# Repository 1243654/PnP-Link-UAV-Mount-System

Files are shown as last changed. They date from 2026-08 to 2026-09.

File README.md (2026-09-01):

# PnP-Link-UAV-Mount-System
无人机多兼容智能挂载系统，包含机械脱钩结构设计、控制固件与通信协议。本项目为 2026 中美创客大赛参赛作品，按赛事开源评分要求完整公开全部技术方案。

## 项目概述
本项目完整名称为**多兼容型智能无人机挂载系统**完整英文名为“Multi-Compatible Intelligent UAV Payload System”，包含机械脱钩结构设计、3D打印结构件、STM32控制固件与PnP-Link通信协议，可实现不同载荷的快速换装与标准化控制。

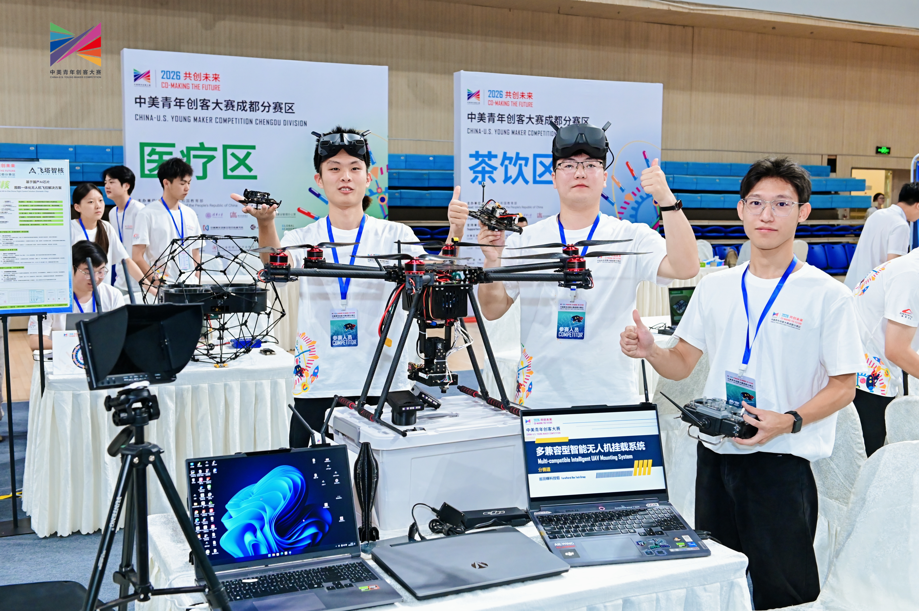
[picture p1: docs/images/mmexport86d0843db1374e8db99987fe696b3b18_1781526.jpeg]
合照


## 项目功能
多兼容型智能无人机挂载系统，首创“挂载臂（母座）+子挂载（公头）”分离式架构，彻底打破无人机“一机一用”的局限。
挂载臂固定于无人机底部，集成自稳控制、智能识别与供电管理；子挂载为可更换任务模块，涵盖空投器、喊话器、喷雾器等。两者通过定制6触点热插拔接口连接，采用长短针物理顺序设计，确保插入时地线最先接通、拔出时检测脚最先断开，从硬件层面杜绝热插拔损坏。子挂载插入后自动上报类型码，挂载臂半秒内完成识别与锁定，全程无需工具、无需调参，真正即插即用。
安全方面，系统同时监测EN电气触点、机械微动开关、串口心跳包三重独立信号，经组合逻辑判断约7种故障类型并分级报警。只有三信号同时确认物理脱离，才触发紧急断电，彻底杜绝振动环境下的误脱钩。插销式对称锁定机构带机械自锁斜面，舵机断电后仍保持锁紧。自稳控制采用独有角速度阻尼算法，不依赖飞控、不对抗飞控，有效抑制加减速与气流引起的摆动。
一套挂载臂兼容无限子挂载，让无人机像换相机镜头一样切换任务，真正实现一机多能、降本增效。

## 基本逻辑
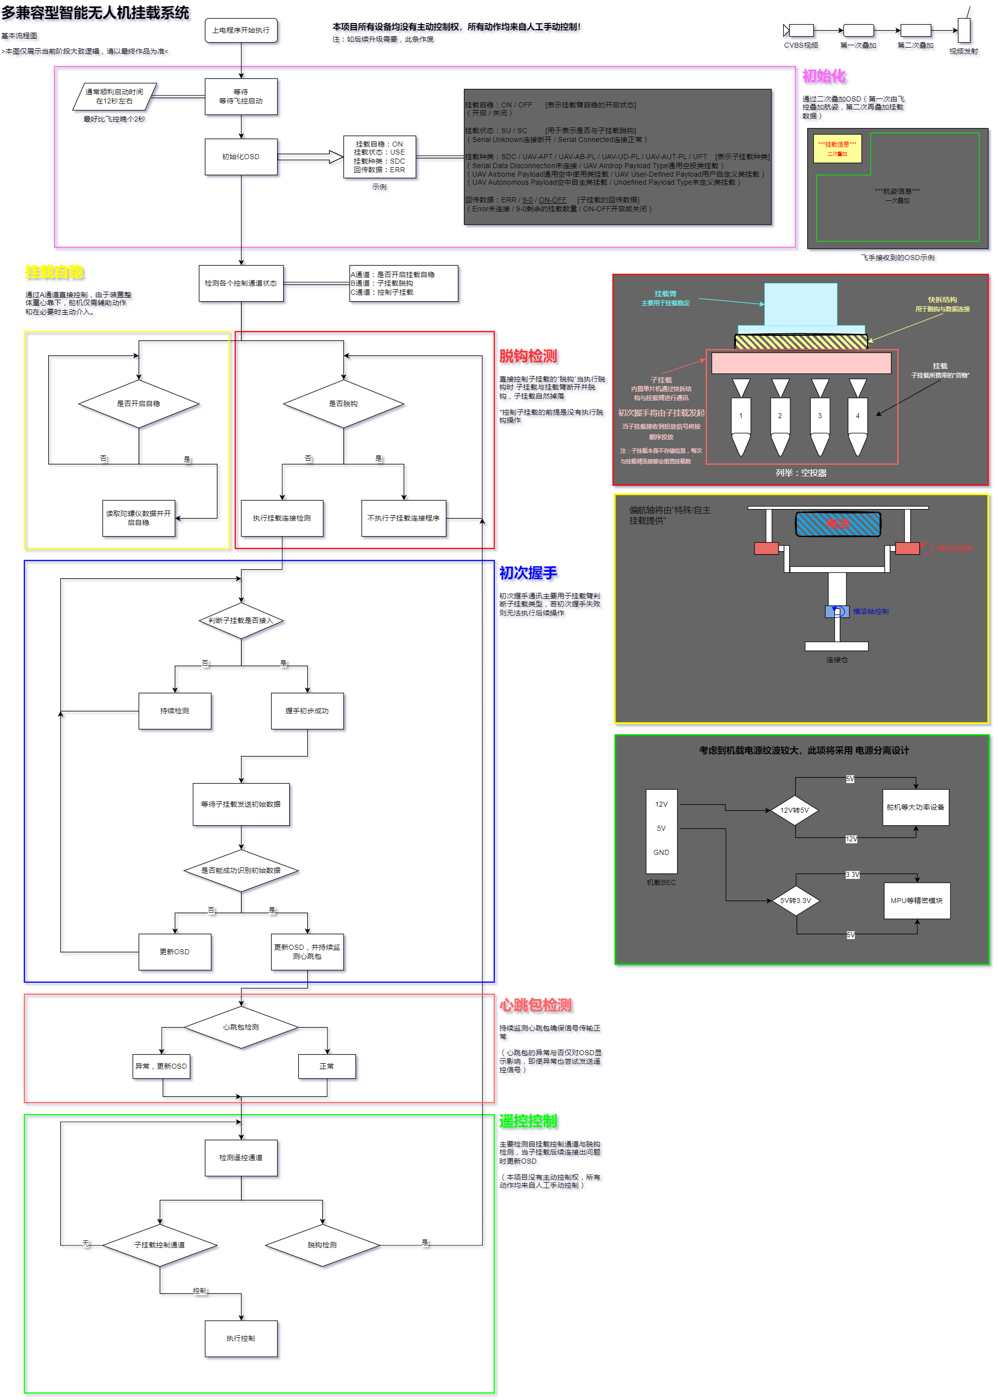
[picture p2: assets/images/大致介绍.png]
工作逻辑


## 接口介绍
考虑到无人机热插拔的特殊性，本设计为其提供5V 12V供电以适配绝大部分子设备供电需求，使用顺序接入触点在物理层面杜绝热插拔损坏。
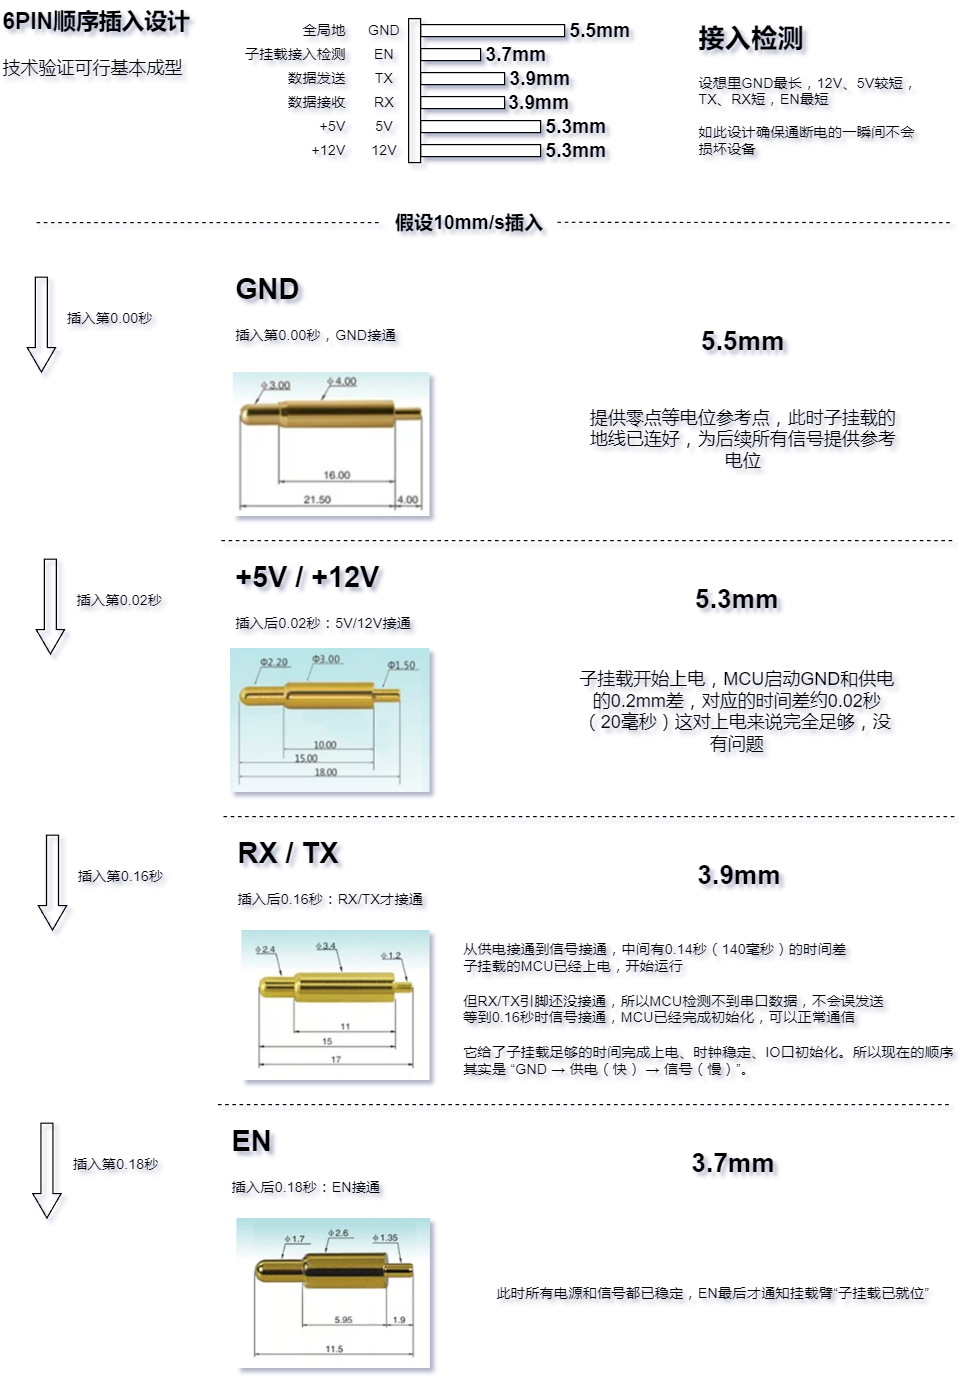
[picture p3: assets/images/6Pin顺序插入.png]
触点


## P&P Link
本协议经过多次优化目前效果较好，其优势有端到端极低延迟：约 5到10ms（主循环 100Hz，串口 115200bps，单帧最小 7 字节 约0.6ms 传输）、稳定运行频率主循环 100Hz，心跳超时 3000ms，无 ACK 开销，纯单工发送无拥塞控制、协议仅用作挂载控制链路（子设备 PWM 转发 + 心跳），不承担飞控与地面站主链路通信
完整帧结构为：
0xAA | main_id | sub_id | type | data_len | data(0~255B) | checksum | 0x55
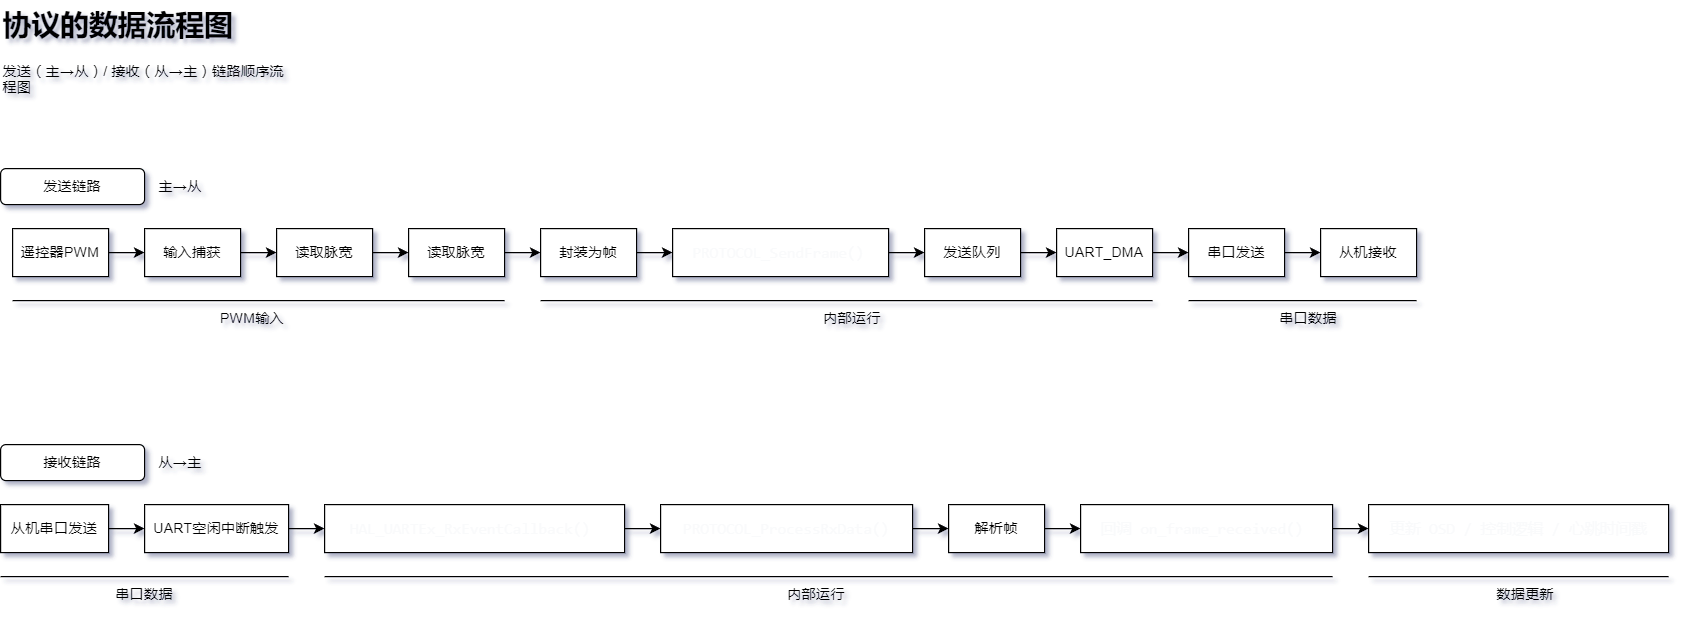
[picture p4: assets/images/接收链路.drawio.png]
协议逻辑


本项目为 **2026中美创客大赛** 参赛作品，按赛事「开源共享」评分要求完整公开全部技术方案。

## 发布信息
- **首次公开日期**：2026年7月8日
- **开发主导**：MXXS
- **协作开发**：YE

## 关键声明
1. 本项目全部技术方案（含机械结构、控制算法、通信协议）已完整公开。
2. 本项目采用 MIT 许可证开源，任何人可自由学习、使用与修改，详见 LICENSE 文件。
3. 项目附属的P&P-Link(PnP-Link)协议均为原创。

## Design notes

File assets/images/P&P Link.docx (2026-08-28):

P&P Link 通讯协议全自研

Plug & Play Link —— 即插即用串行链路协议

P&P Link 是一套轻量级、高可靠的串行通讯协议，通过帧头帧尾校验 + 主从ID寻址 + DMA高效收发 + 心跳保活机制，实现了无人机挂载系统的“插上即识别、在线即感知、指令即执行”的智能热插拔通讯能力。

协议帧结构（底层格式）

字段 | 长度 | 值/说明
帧头 | 1字节 | 固定0XAA
主ID | 1字节 | 设备大类（如 0x01=空投器类）
子ID | 1字节 | 设备小类（同一大类下的不同型号）
类型码 | 1字节 | 帧类型（0x01=心跳，0x02=控制数据等）
数据长度 | 1字节 | 后续数据字节数（0~255）
数据 | N字节 | 具体载荷
帧尾 | 1字节 | 固定0x55

最大帧长度：255 + 7 = 262 字节

接入逻辑：

1.握手识别

硬件触发：微动开关 A 检测到上升沿（子挂载插入），触发 CheckKeys() 中的插入检测逻辑：

// 上升沿检测（插入）

if (micro_state == GPIO_PIN_SET && last_micro_state == GPIO_PIN_RESET) {

// 彻底重置串口3

HAL_UART_DMAStop(&huart3);

__HAL_UART_CLEAR_IDLEFLAG(&huart3);

memset(protocol_rx_buf, 0, RX_BUF_SIZE);

// 重新初始化协议库

PROTOCOL_Init(&huart3, protocol_rx_buf, RX_BUF_SIZE);

PROTOCOL_RegisterCallback(MAIN_ID_ANY, SUB_ID_ANY, on_frame_received);

Debug_Print("Mount inserted, UART3 reset\r\n");

last_micro_state = GPIO_PIN_SET;

}

2.载上电发送类型码：

子挂载插入后获得供电（5V/12V），其 MCU 启动后自动通过串口发送包含设备类型码的握手帧。

3.臂接收并识别：

on_frame_received() 回调函数接收到帧后，解析 main_id（主ID）并更新 OSD 显示：

// 挂载类型显示（仅在类型变化时更新 OSD）

if (main_id != last_main_id) {

last_main_id = main_id;

switch (main_id) {

case 0x01:

OSD_Disply_String(4, 7, "UAV-APT"); // 空投器

OSD_Disply_String(5, 7, "ON ");

break;

case 0x02:

OSD_Disply_String(4, 7, "UAV-AB-PL"); // 其他挂载

OSD_Disply_String(5, 7, "ON ");

break;

default:

OSD_Disply_String(4, 7, "UPT"); // 未知类型

OSD_Disply_String(5, 7, "ERR");

break;

}

}

使用MAIN_ID_ANY（0xFF）注册回调，意味着任何主ID的子挂载都能被识别，无需预先知道具体类型——真正实现了“即插即用”。

心跳保持：

1.载定期发送心跳帧：子挂载每 200ms（5Hz）发送一个 type=0x01 的心跳帧。

2.臂接收并更新时间戳：

if (type == 0x01) {

// 心跳包：通知挂载监控

MM_OnHeartbeatReceived();

last_heartbeat_tick = HAL_GetTick(); // 记录心跳时间

// ... 显示设备类型等

}

3.超时检测：主循环中判断心跳是否超时：

uint8_t heartbeat_ok = (HAL_GetTick() - last_heartbeat_tick) < HEARTBEAT_TIMEOUT_MS;

if (!heartbeat_ok) {

// 已接入但心跳丢失 -> 红灯（故障）

HAL_GPIO_WritePin(R_GPIO_Port, R_Pin, GPIO_PIN_SET);

HAL_GPIO_WritePin(G_GPIO_Port, G_Pin, GPIO_PIN_RESET);

HAL_GPIO_WritePin(B_GPIO_Port, B_Pin, GPIO_PIN_RESET);

}

超时时间：3000ms（代码中 #define HEARTBEAT_TIMEOUT_MS 3000），允许一定的网络延迟和抖动。

指令下发：

1.飞手拨动摇杆：遥控器通道信号通过 PWM 输入捕获读取。

2.挂载臂封装指令：将 PWM 脉宽值（1000~2000μs）编码为 2 字节数据：

for (int i = 0; i < 4; i++) {

uint16_t pulse = PWM_Input_GetPulse(&rc_ch3[i]);

// 信号有效性判断...

if (pulse != last_pulse[i]) {

last_pulse[i] = pulse;

uint8_t data[2] = {

(uint8_t)(pulse & 0xFF),

(uint8_t)((pulse >> 8) & 0xFF)

};

PROTOCOL_SendFrame(0x01, sub_ids[i], 0x02, data, 2);

}

}

3.指令帧格式：

主ID = 0x01（通用挂载类）

子ID = 0x01~0x04（对应 4 个通道）

类型码 = 0x02（控制数据）

数据 = PWM 脉宽值（小端序 2 字节）

4.子挂载响应：子挂载收到指令后执行对应动作（如开启喷洒、释放脱钩等）。

脱钩感知：

1.硬件触发：微动开关 A 检测到下降沿（子挂载拔出）。

2.软件响应：

// 下降沿检测（拔出）

else if (micro_state == GPIO_PIN_RESET && last_micro_state == GPIO_PIN_SET) {

// 拔出时也重置串口，以便下次插入正常工作

HAL_UART_DMAStop(&huart3);

__HAL_UART_CLEAR_IDLEFLAG(&huart3);

PROTOCOL_Init(&huart3, protocol_rx_buf, RX_BUF_SIZE);

PROTOCOL_RegisterCallback(MAIN_ID_ANY, SUB_ID_ANY, on_frame_received);

Debug_Print("Mount removed, UART3 reset\r\n");

last_micro_state = GPIO_PIN_RESET;

}

3.OSD 更新：拔出后，OSD 显示“SDC”（Serial Data Disconnection，串行数据未连接）：

OSD_Disply_String(4, 7, "SDC ");

OSD_Disply_String(5, 7, "OFF");

“三重故障检测”的协同工作

P&P Link 协议与三重故障检测（EN脚、微动开关、心跳包）形成闭环：

检测项 | 代码中实现 | 作用
EN脚 | HAL_GPIO_ReadPin(EN_GPIO_Port, EN_Pin) | 检测电气连接是否在位
微动开关 | HAL_GPIO_ReadPin(MICROSWITCH_A_GPIO_Port, MICROSWITCH_A_Pin) | 检测子挂载是否完全插入/拔出
心跳包 | last_heartbeat_tick + 超时判断 | 检测子挂载程序是否存活

DMA 接收关键代码：

void HAL_UARTEx_RxEventCallback(UART_HandleTypeDef *huart, uint16_t Size)

{

if (huart == &huart3) {

PROTOCOL_ProcessRxData(protocol_rx_buf, Size);

HAL_UART_DMAStop(huart);

HAL_UARTEx_ReceiveToIdle_DMA(huart, protocol_rx_buf, RX_BUF_SIZE);

}

}

采用 DMA + 空闲中断 方式，CPU 不参与每个字节的接收，只有在收到完整一帧（或超时）时才触发中断处理，效率极高。

协议的扩展性设计

1.主ID/子ID二级寻址：支持最多 255×255 种设备类型组合

2.回调函数注册机制：PROTOCOL_RegisterCallback(MAIN_ID_ANY, SUB_ID_ANY, on_frame_received) 支持不同设备注册不同处理函数

3.类型码扩展：已有 0x01（心跳）和 0x02（控制数据），可继续扩展 0x03~0xFF

P&P Link 协议通过以下设计实现了“即插即用、实时通讯”：

设计目标 | 实现方式 | 代码体现
即插即用 | 上电自动发送类型码，挂载臂自动识别 | on_frame_received解析main_id，无需预设
实时感知 | 5Hz 心跳包 + 3秒超时检测 | last_heartbeat_tick+ HEARTBEAT_TIMEOUT_MS
双向控制 | 下行指令帧 + 上行状态反馈 | PROTOCOL_SendFrame+ on_frame_received
热插拔支持 | 微动开关检测插入/拔出，自动重置串口 | CheckKeys()中的上升沿/下降沿检测
硬软协同 | EN脚 + 微动开关 + 心跳包三重检测 | RGB指示灯逻辑
系统解耦 | 协议库独立，通过回调函数与业务逻辑分离 | PROTOCOL_RegisterCallback+ 回调函数

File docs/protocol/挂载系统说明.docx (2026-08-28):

# 多兼容型智能无人机挂载系统

一、项目背景（选题背景、目的与意义）

1. 选题背景

近年来，多旋翼无人机在航拍、物流、农业、应急救援等领域得到广泛应用。然而，大多数无人机挂载系统存在以下痛点：

- 功能单一：一个挂架只能适配一种任务载荷（如仅能投掷或仅能喷洒），更换载荷需要落地手动拆装，效率低。
- 缺乏智能交互：飞手无法实时获知挂载物的连接状态、设备类型及健康度，脱钩操作仅靠机械解锁，可靠性差。
- 自稳与飞控耦合：传统自稳云台需与飞控深度通信，增加了系统复杂度，且容易与飞控PID产生振荡。
- 热插拔能力弱：绝大多数挂载接口不具备带电插拔保护，易损坏电路。

2. 项目目的

本项目旨在设计一套 “多兼容型智能无人机挂载系统” ，实现：

- 即插即用：子挂载可空中不停机更换，自动识别类型并建立通信。
- 独立自稳：挂载臂内置姿态传感器，以“辅助阻尼”方式保持负载水平实现“辅助稳定”+“摆动抑制”，不与飞控PID耦合。
- 高可靠性：通过三重故障检测（电气触点、机械锁紧、心跳包）实现精准脱钩判断。
- 模块化扩展：支持空投器、拉烟器、喷雾器等多种任务载荷。

3. 项目意义

- 降低无人机任务门槛：飞手无需专业编程知识，即可快速切换任务模式。
- 提升作业安全性：多重检测与容错设计，避免误脱钩或挂载脱落。
- 推动开源硬件生态：系统采用标准化接口与通信协议，可被社区广泛复用，促进无人机挂载技术的普及。

二、项目创新点（创新点与特色）

创新点 | 具体描述 | 技术细节
热插拔与自动识别 | 6触点采用长短针设计（GND最长→电源→信号→检测脚），保证插入/拔出顺序安全；子挂载上电即发送类型码，挂载臂自动记录并锁定 | 硬件顺序保护+串口握手协议
独立自稳辅助系统 | 挂载臂内置MPU6500陀螺仪，仅采用角速度阻尼控制（D控制），无需与飞控通信，避免耦合振荡，在2kg负载/20cm力臂下摆动幅度降低80%以上。 | 卡尔曼滤波+单轴阻尼控制
三重故障检测与脱钩判定 | 同时监测EN触点（电气连接）、微动开关（机械锁紧）、心跳包（程序活性），根据组合状态判断故障类型（连接性故障/结构性故障/逻辑性故障/异常脱钩），并分级报警。 | 状态机+去抖滤波
插销式对称锁定机构 | 一个舵机通过连杆同时驱动左右两个插销，锁定子挂载；插销到位触发微动开关，形成闭环反馈；可增加自锁斜面，防止舵机断电意外脱钩。 | 机械创新+位置传感器
模块化软件架构 | 挂载臂与子挂载分别采用独立单片机，通过简化的串口协议通信（类型码、心跳包、告别帧），不依赖飞控数据，易移植至不同平台。 | USART+状态机

三、运行逻辑

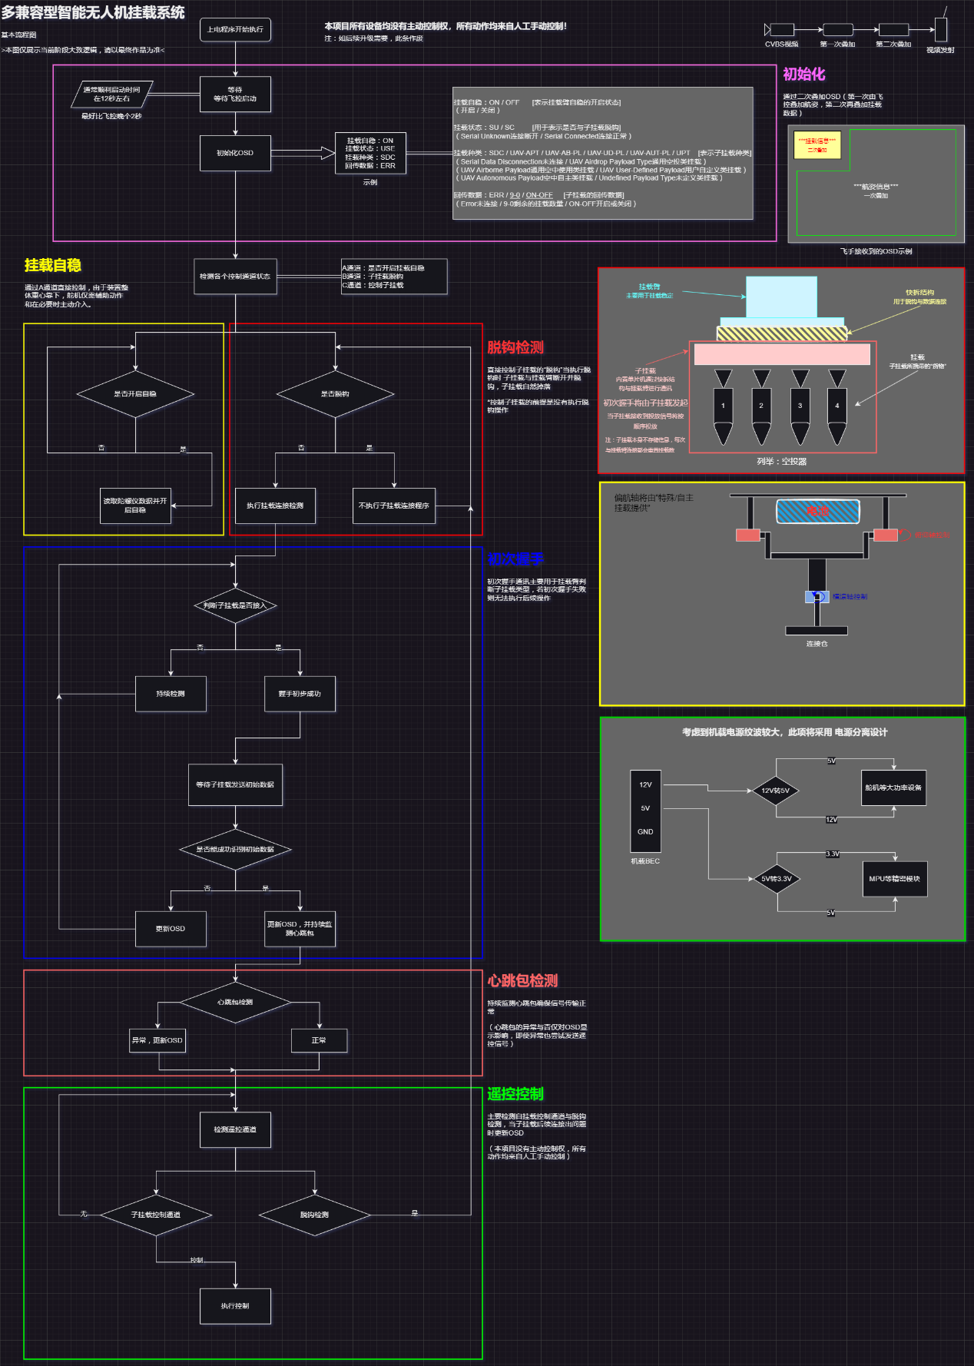
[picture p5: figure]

三、心跳包与检测冗余设计

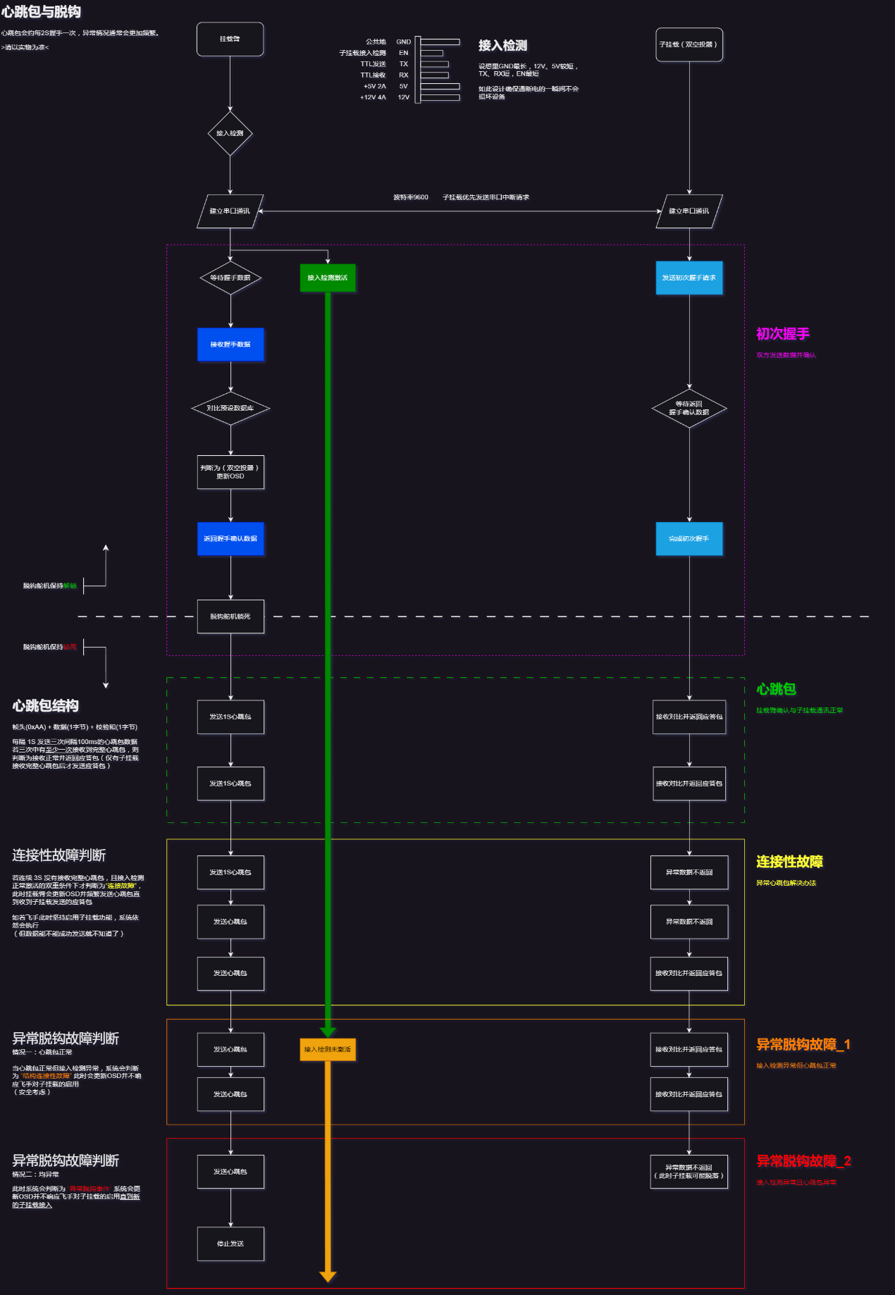
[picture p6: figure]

四、快拆接口设计

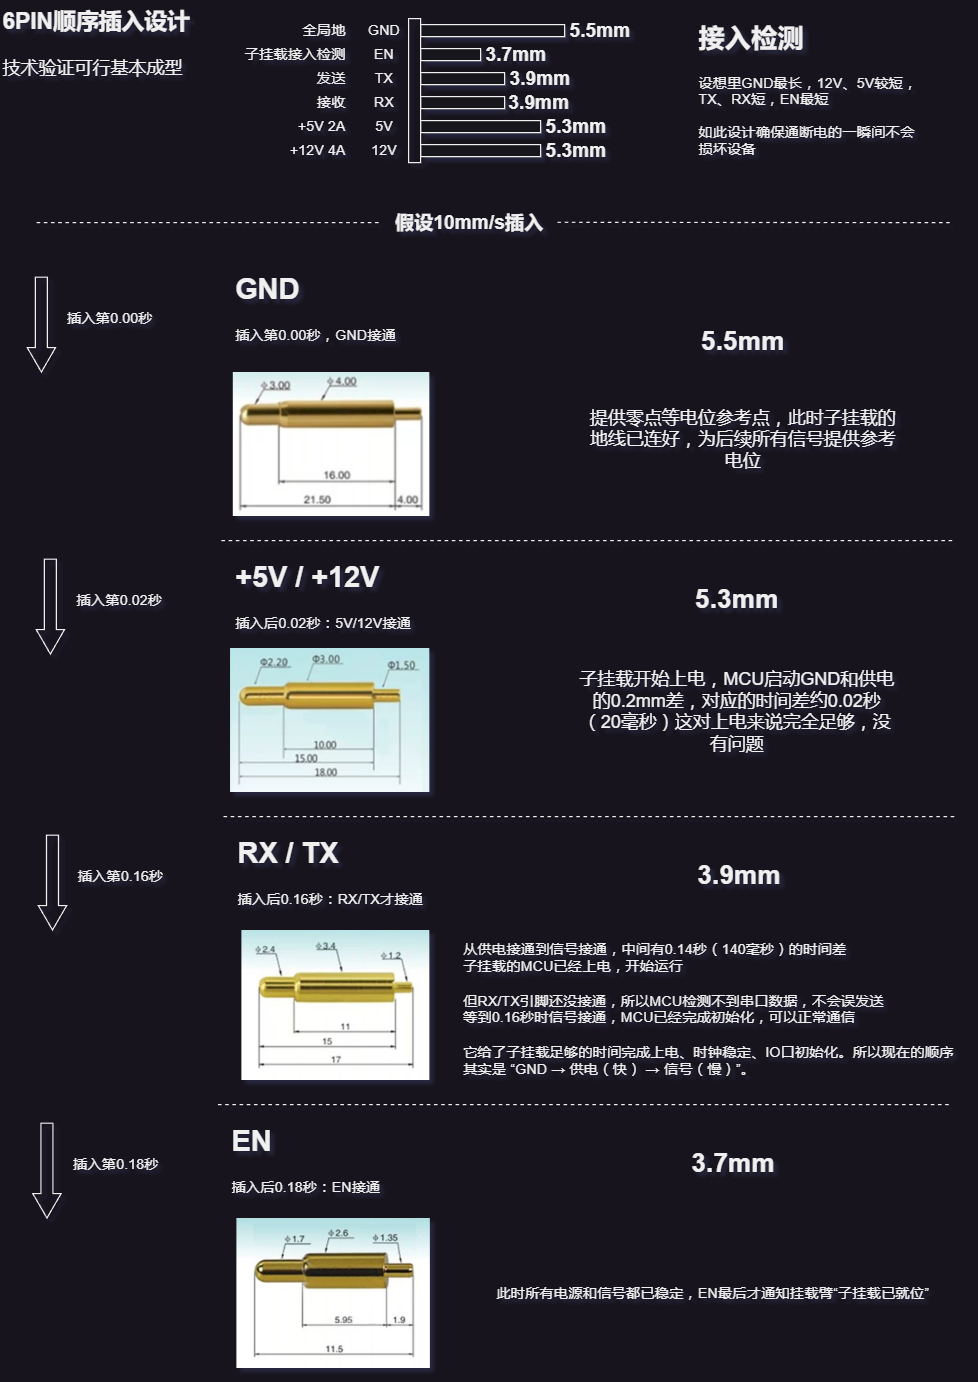
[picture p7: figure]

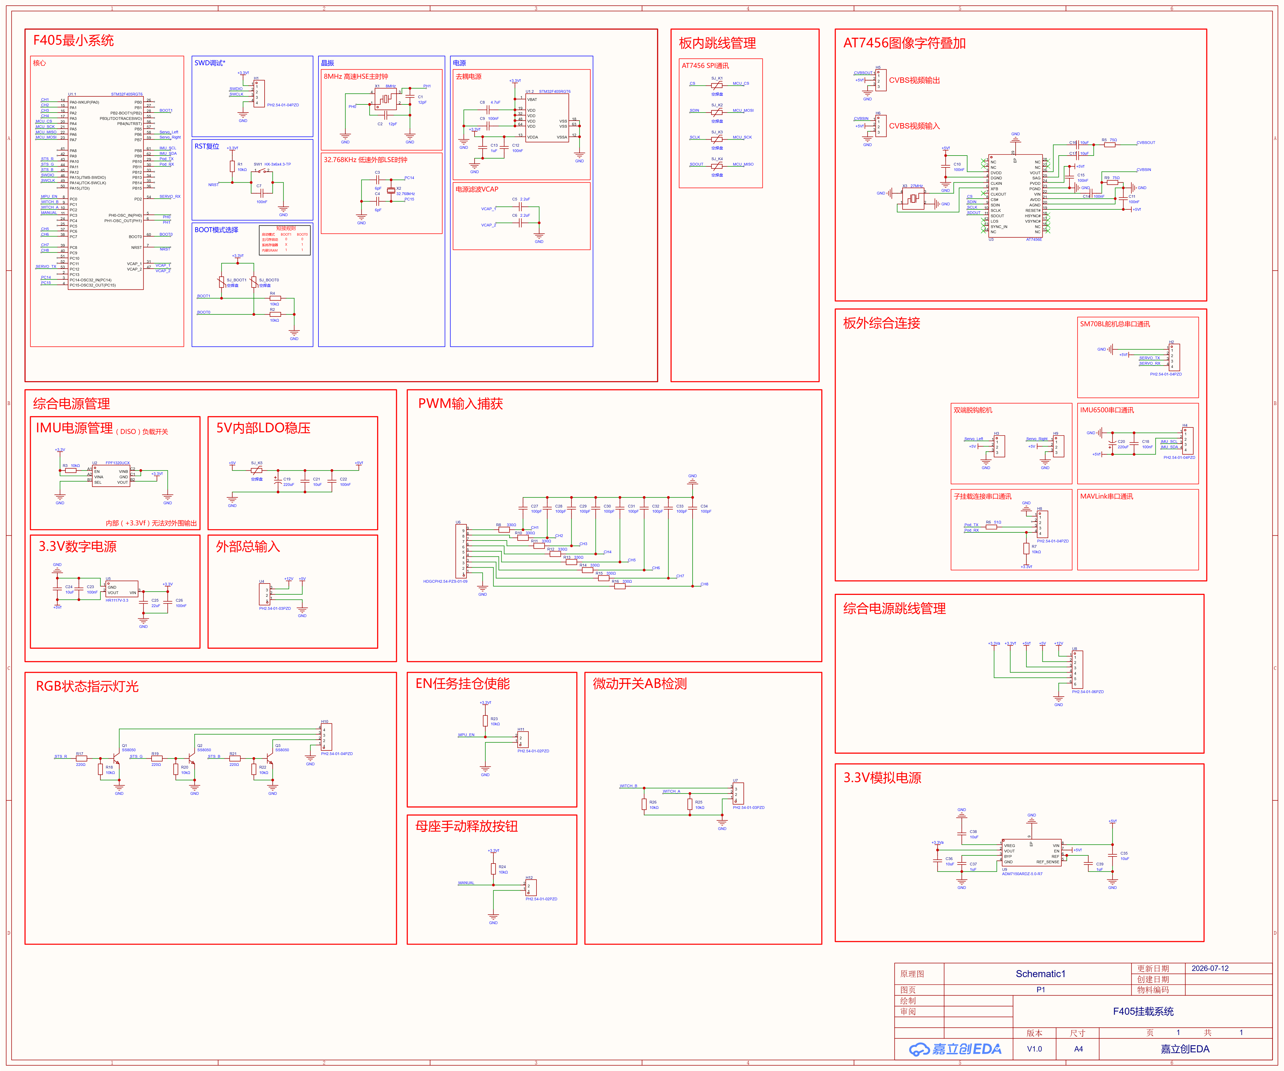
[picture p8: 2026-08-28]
docs/images/原理图.png

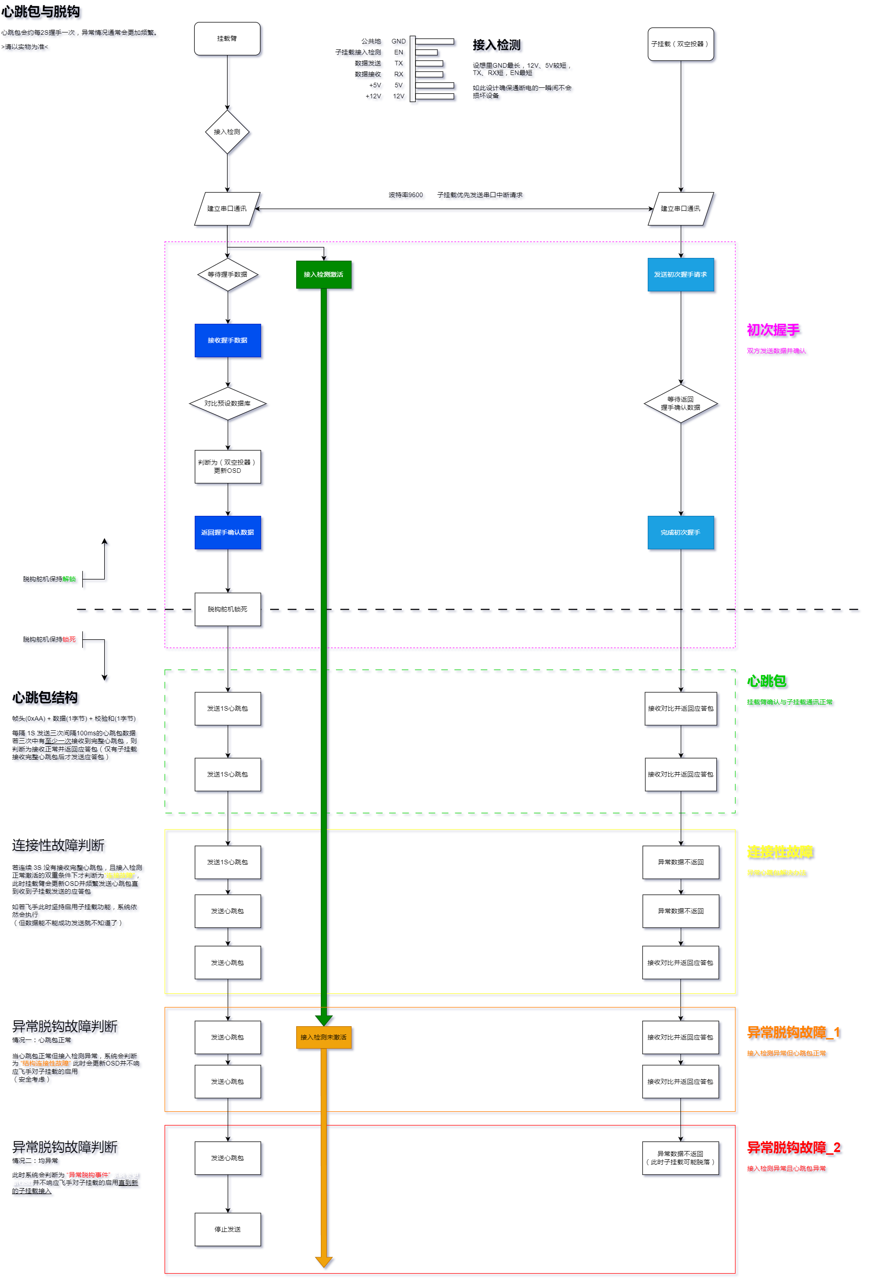
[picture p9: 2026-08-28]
docs/images/P&P Link逻辑.png

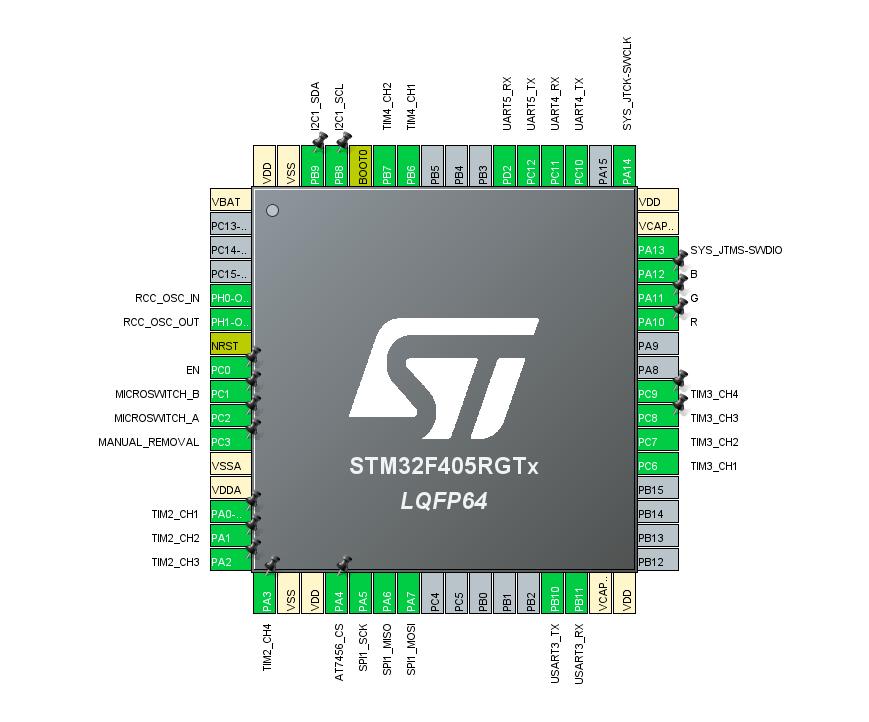
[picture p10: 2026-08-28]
docs/images/硬件配置图.png

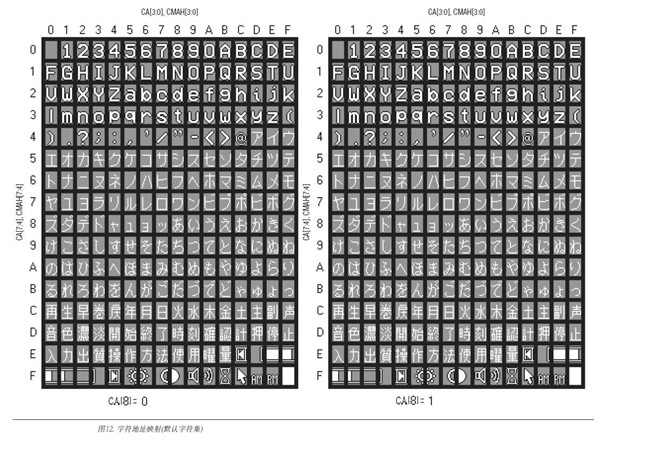
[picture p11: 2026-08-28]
assets/OSD/图片1.jpg

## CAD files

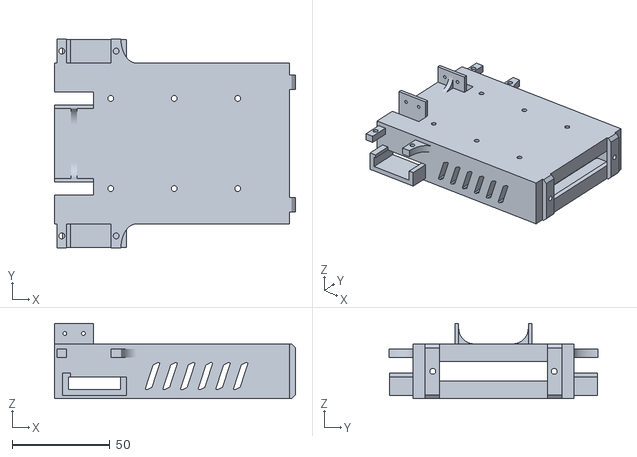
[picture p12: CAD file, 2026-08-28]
hardware/stl/挂载臂母座总成.stl
123.0 x 106.6 x 38.5

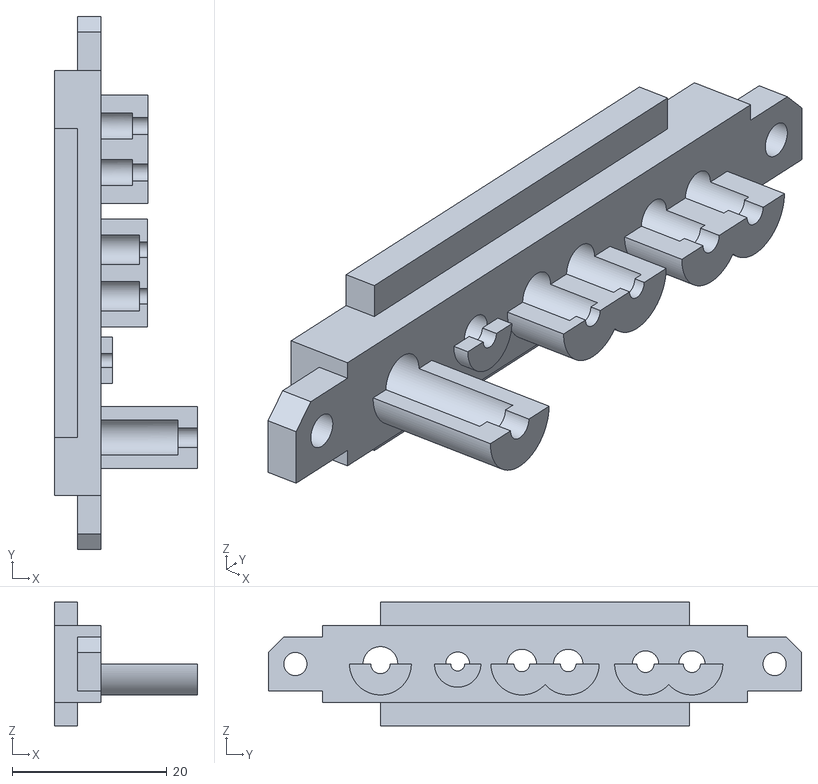
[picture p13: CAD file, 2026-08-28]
hardware/stl/触点接口固定外壳.stl
18.5 x 69.0 x 16.0

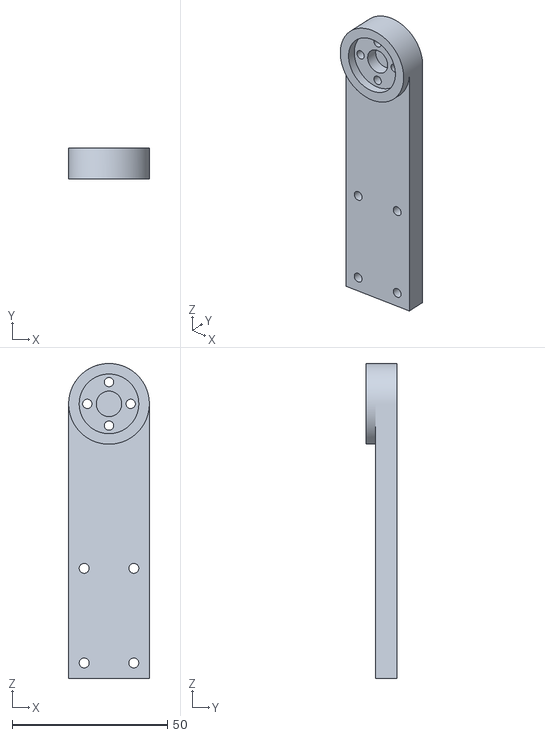
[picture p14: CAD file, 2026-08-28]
hardware/stl/挂载臂俯仰轴舵机摇臂.stl
26.0 x 10.0 x 101.5

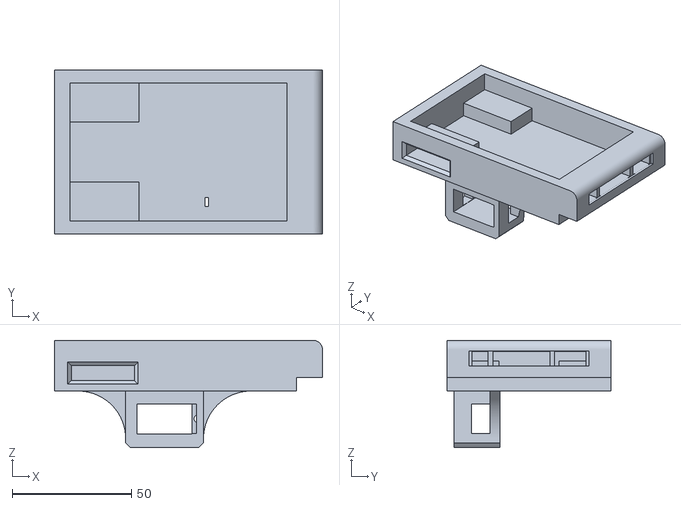
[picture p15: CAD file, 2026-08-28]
hardware/stl/通用单挂空投器.stl
112.5 x 69.0 x 45.1

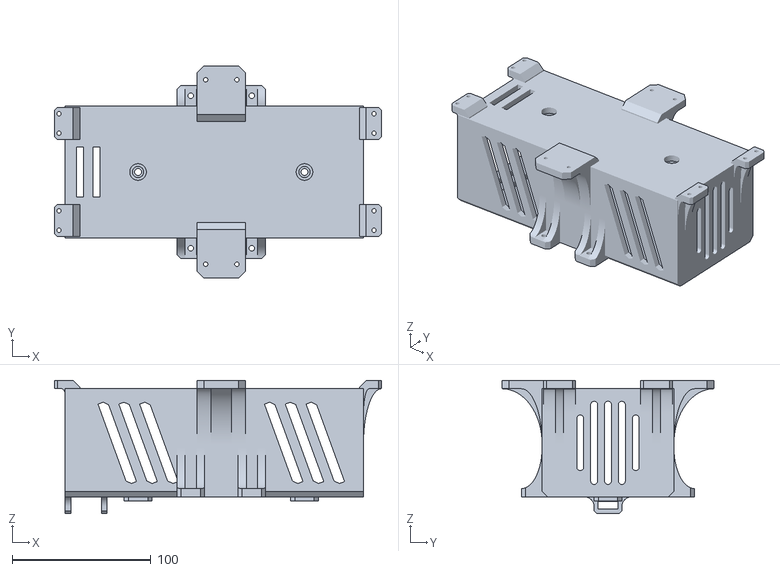
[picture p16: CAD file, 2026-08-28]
hardware/stl/电池挂仓+下连接点.stl
235.8 x 153.0 x 96.0

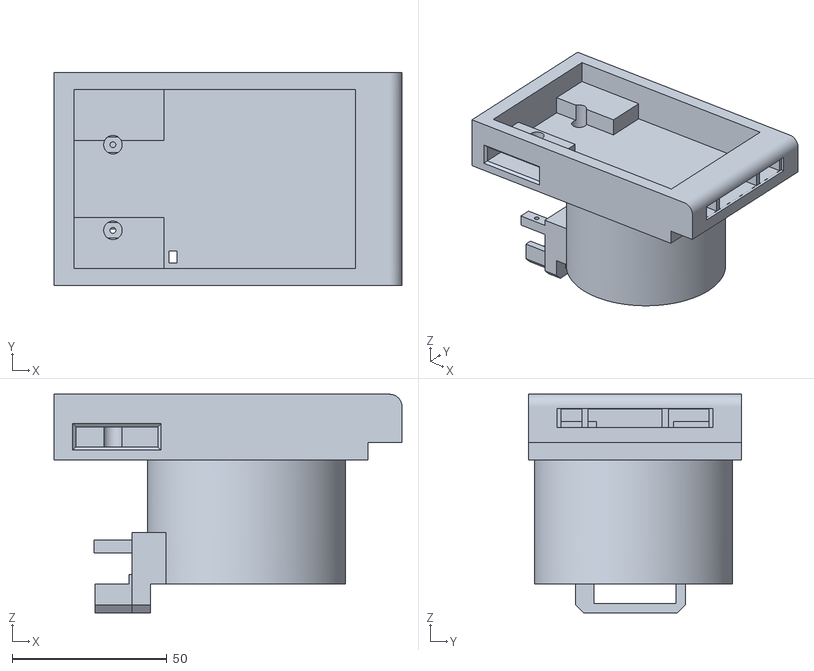
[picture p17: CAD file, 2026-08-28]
hardware/stl/适用于60式迫击炮弹空投器.stl
112.5 x 69.0 x 70.6

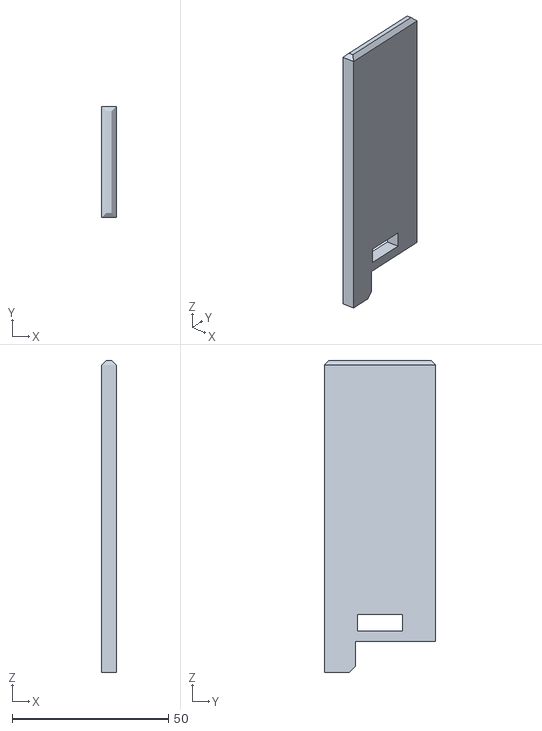
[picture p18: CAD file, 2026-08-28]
hardware/stl/电池挂仓挡板.stl
4.70 x 35.7 x 100.0

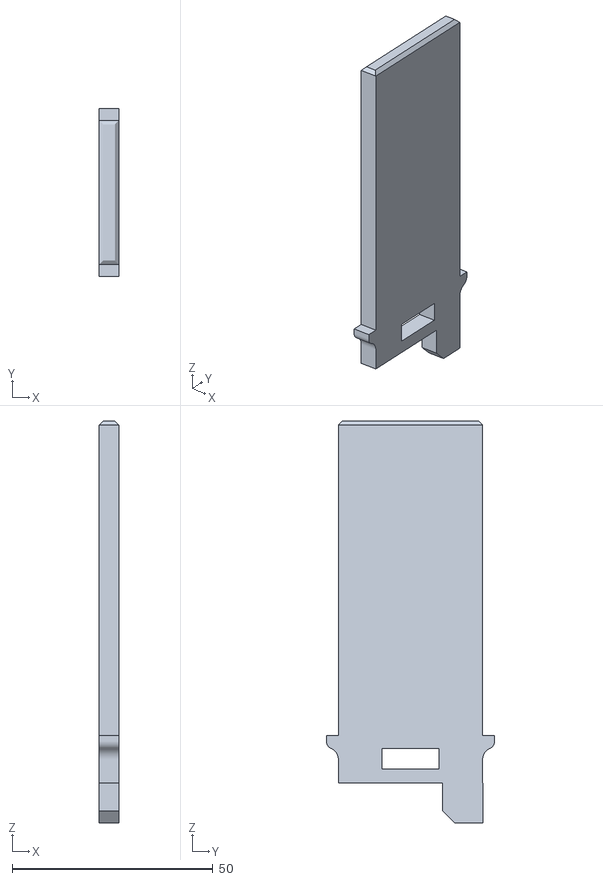
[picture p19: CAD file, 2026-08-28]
hardware/stl/电池挂仓挡板改.stl
4.90 x 41.9 x 100.0

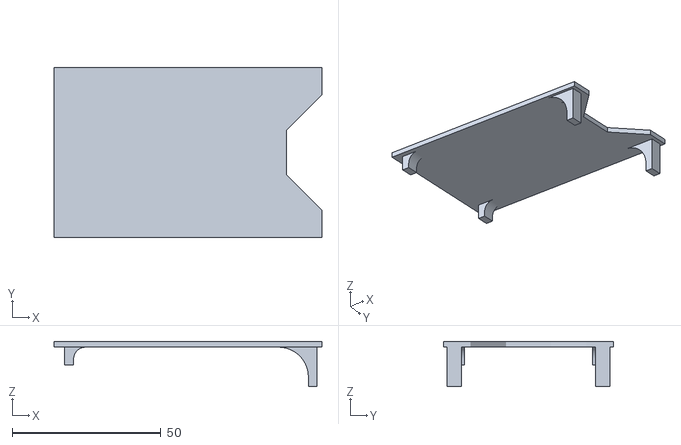
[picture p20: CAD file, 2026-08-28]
hardware/stl/任务挂仓顶盖.stl
90.2 x 57.3 x 15.3

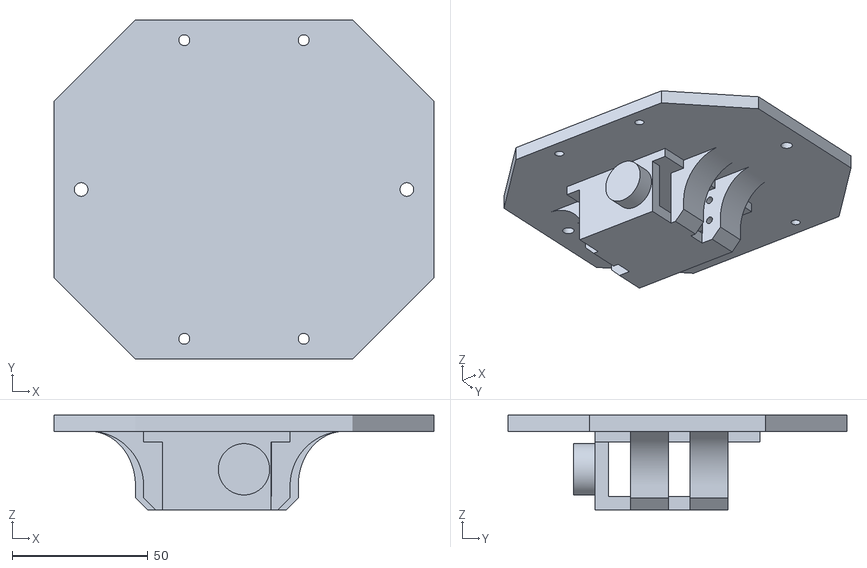
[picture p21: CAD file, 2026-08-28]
hardware/stl/挂载臂俯仰轴固定底座.stl
140.0 x 125.0 x 35.0

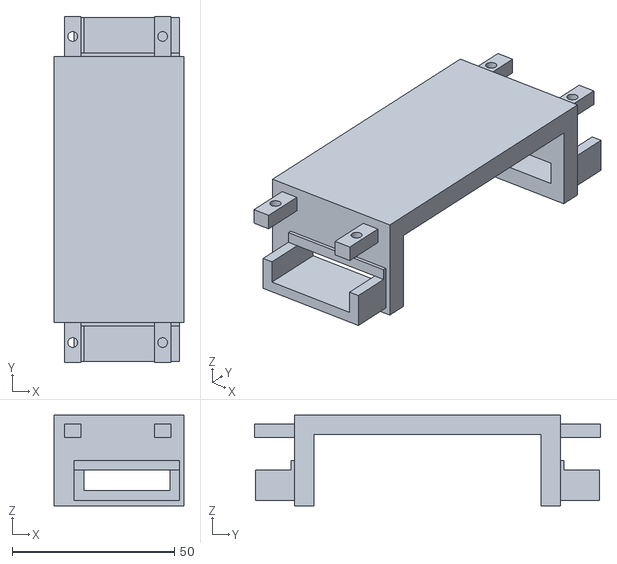
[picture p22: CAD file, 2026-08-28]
hardware/stl/测试用双端SG90S脱钩打印件.stl
40.0 x 106.6 x 28.0

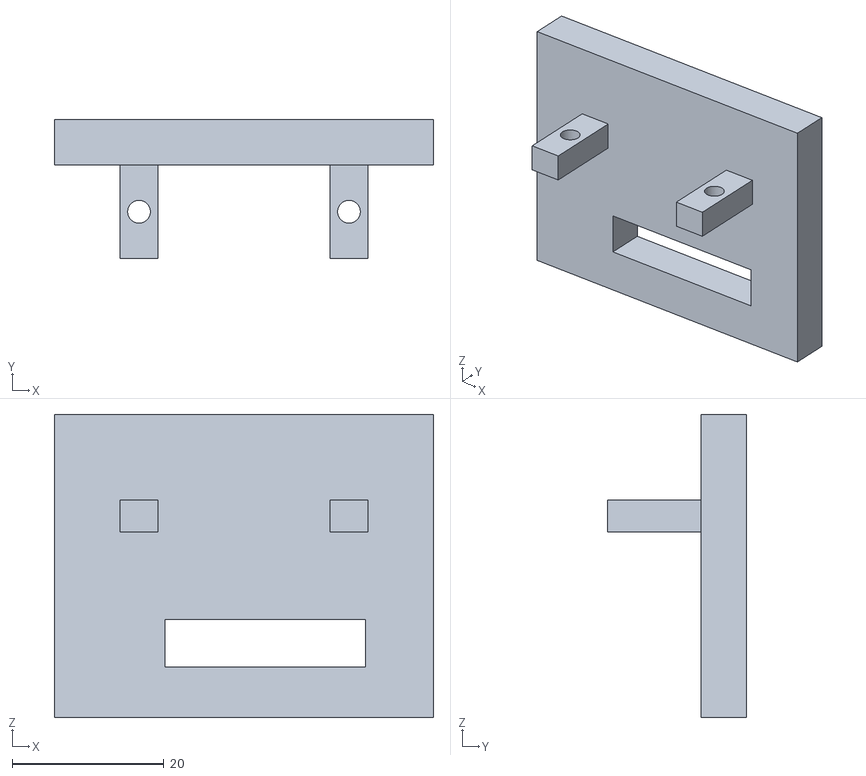
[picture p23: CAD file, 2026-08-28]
hardware/stl/测试用单端快拆结构打印件.stl
50.0 x 18.3 x 40.0

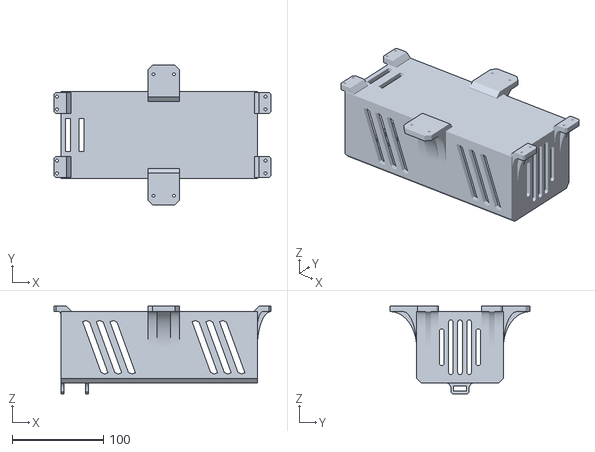
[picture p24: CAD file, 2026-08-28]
hardware/stl/适用于10000mAh-16000mAh 6S航模电池挂仓.stl
237.8 x 153.0 x 96.0

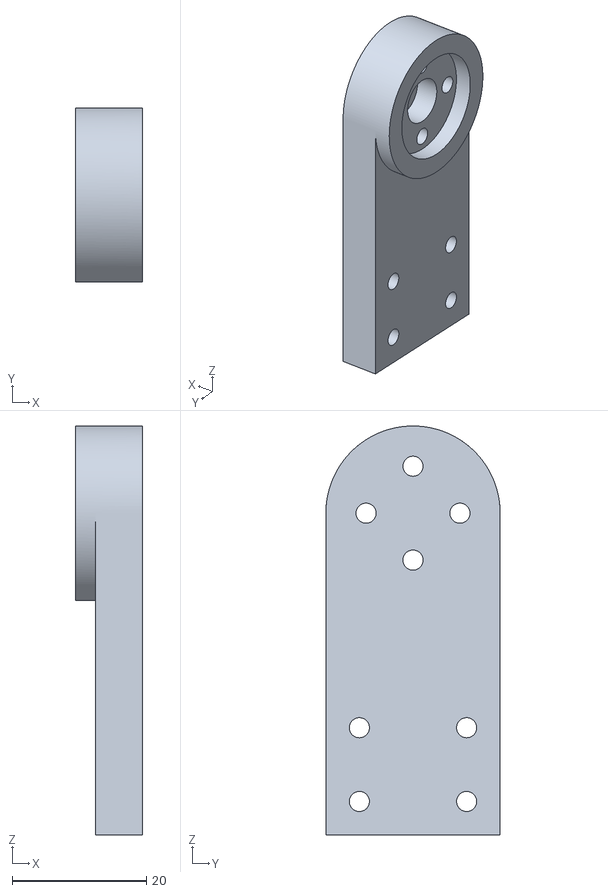
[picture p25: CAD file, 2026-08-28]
hardware/stl/挂载臂横滚轴舵机摇臂.stl
10.0 x 26.0 x 61.0

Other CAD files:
hardware/stl/电池挂仓锁销.stl
hardware/stl/测试用任务挂仓连接打印件.stl
hardware/stl/适用于SG90S空投器摇臂接口.stl
hardware/stl/通用双联空投器.stl
hardware/stl/60式迫击炮弹.stl
hardware/stl/单方插销.stl
hardware/stl/挂载臂俯仰轴后端接口+横滚轴舵机底座.stl
hardware/stl/挂载臂横滚轴舵机后端接口.stl
hardware/stl/测试用触点母座打印件.stl
hardware/stl/电池挂仓锁销改.stl

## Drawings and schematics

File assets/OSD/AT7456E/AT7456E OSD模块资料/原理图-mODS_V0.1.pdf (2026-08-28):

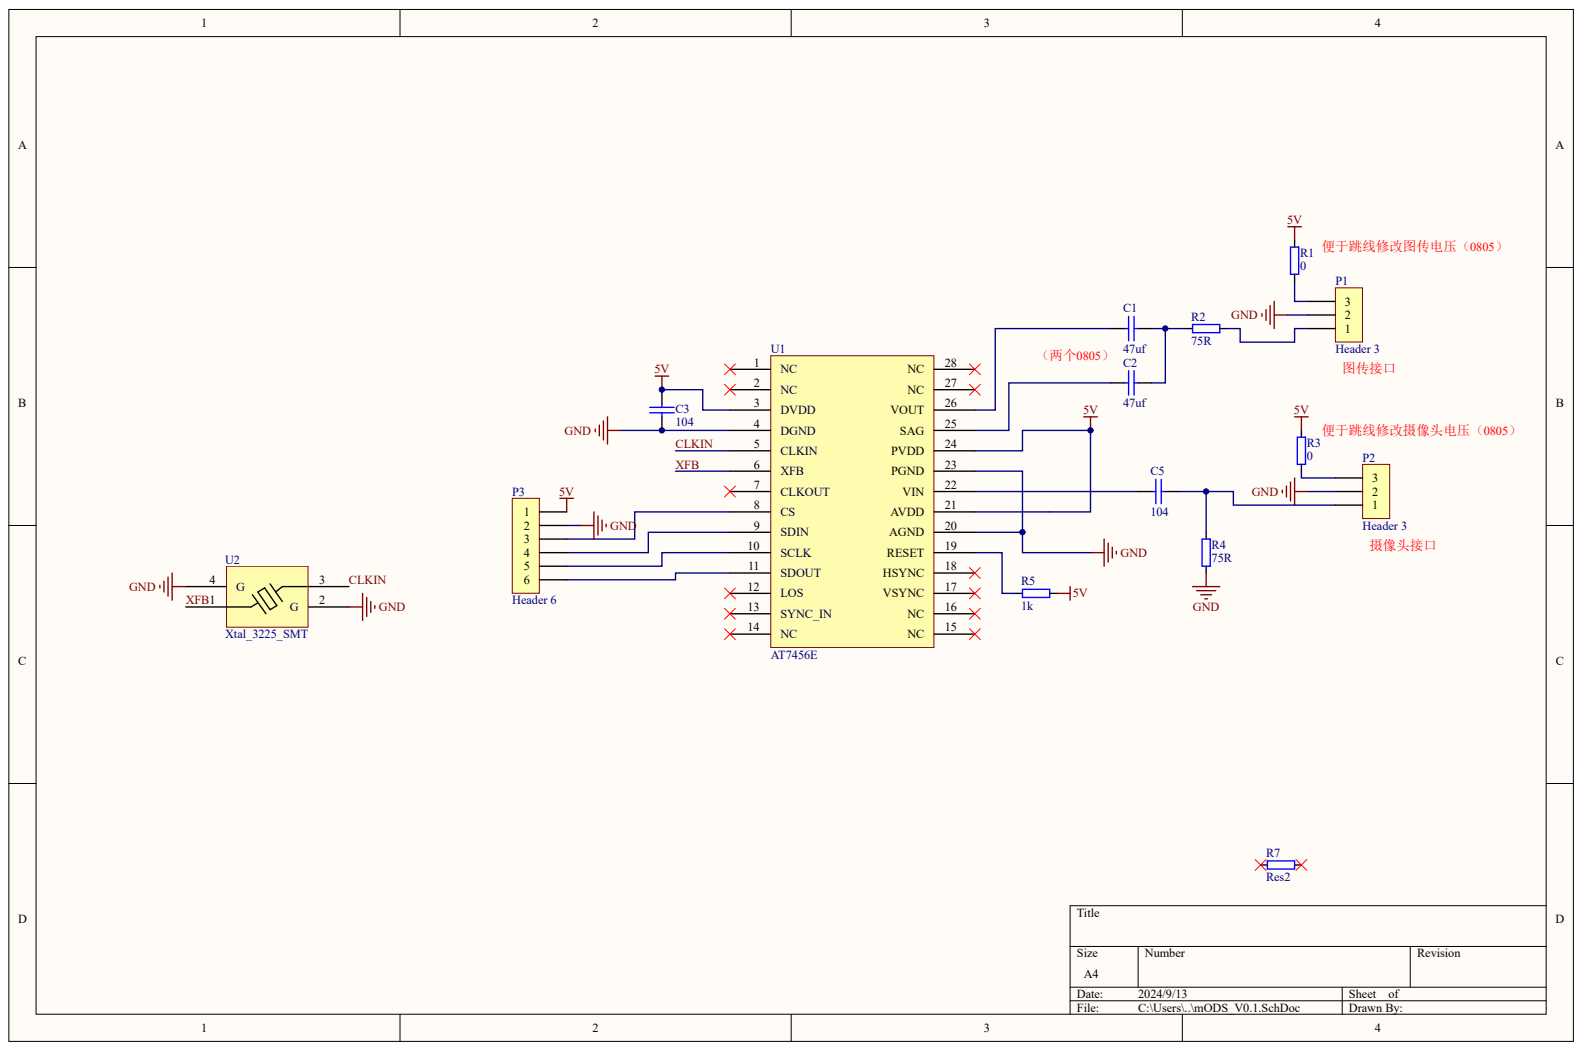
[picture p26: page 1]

Comment | Description | Designator | Footprint | LibRef | Quantity
47uf | | C1, C2 | 0805_CAP | CAP | 2
104 | | C3, C5 | 0603_Cap | CAP | 2
Header 3 | | P1, P2 | IF_Connector_3_1.25mm | Header 3 | 2
Header 6 | | P3 | Header 6 | Header 6 | 1
0 | | R1, R3 | 0805_resistor | Res2 | 2
75R | | R2 | 0603_Resistor | Res2 | 1
75R | | R4 | 0603_Cap | Res2 | 1
1k | | R5 | 0603_Cap | Res2 | 1
Res2 | | R7 | IF_logo | Res2 | 1
AT7456E | | U1 | AT7456E | AT7456E | 1
Xtal_3225_SMT | | U2 | Xtal_3225 | Xtal_3225_SMT | 1

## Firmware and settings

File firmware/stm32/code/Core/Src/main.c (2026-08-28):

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
/* Includes ------------------------------------------------------------------*/
#include "main.h"
#include "dma.h"
#include "i2c.h"
#include "spi.h"
#include "tim.h"
#include "usart.h"
#include "gpio.h"

/* USER CODE BEGIN Includes */
#include "MPU9250.h"
#include "servo_uart.h"
#include "rc_ppm_pwm.h"
#include "servo_pwm.h"
#include "OSD.h"
#include "AT7456E.h"
#include "Base.h"
#include "protocol.h"
#include "mount_monitor.h"
#include <math.h>
#include <stdio.h>   
#include <string.h>  
#include <stdarg.h> 

/* USER CODE END Includes */

/* USER CODE BEGIN PTD */
extern UART_HandleTypeDef huart3;  // 声明串口3句柄
extern UART_HandleTypeDef huart4;  // 声明串口4句柄
extern UART_HandleTypeDef huart5;  // 声明串口5句柄
MPU9250_HandleTypeDef hmpu9250;
Kalman_HandleTypeDef kalman_roll;   
Kalman_HandleTypeDef kalman_pitch;  
PWM_Input_Handle rc_ch[4];	   // TIM2 的 4 个 PWM 输入通道
PWM_Input_Handle rc_ch3[4];    // TIM3 的 4 个 PWM 输入通道
Servo_Handle servo9g_Left;
Servo_Handle servo9g_Right;
static MM_Config_t monitor_cfg;
/* USER CODE END PTD */

/* USER CODE BEGIN PD */
//指示灯------------------------------------------------------------------------
/*(已在main文件中宏定义)
红色指示灯
#define R_Pin GPIO_PIN_10
#define R_GPIO_Port GPIOA

绿色指示灯
#define G_Pin GPIO_PIN_11
#define G_GPIO_Port GPIOA

蓝色指示灯
#define B_Pin GPIO_PIN_12
#define B_GPIO_Port GPIOA

子挂载使能引脚
#define EN_Pin GPIO_PIN_0
#define EN_GPIO_Port GPIOC

子挂载检测微动B
#define MICROSWITCH_B_Pin GPIO_PIN_1
#define MICROSWITCH_B_GPIO_Port GPIOC

子挂载检测微动A
#define MICROSWITCH_A_Pin GPIO_PIN_2
#define MICROSWITCH_A_GPIO_Port GPIOC

手动脱钩
#define MANUAL_REMOVAL_Pin GPIO_PIN_3
#define MANUAL_REMOVAL_GPIO_Port GPIOC

OSD叠加模块的片选引脚CS
#define AT7456_CS_Pin GPIO_PIN_4
#define AT7456_CS_GPIO_Port GPIOA
*/

// 遥控器阈值-----------------------------------------------------------------
#define STABILIZE_THRESHOLD  	 1750   // 通道4 > 1750 开启自稳
#define SWITCH_THRESHOLD     	 1750   // 通道3 > 1750 触发9g舵机

// 遥控器脉宽范围 (us)--------------------------------------------------------
#define RC_MIN_PULSE         	 1000
#define RC_MAX_PULSE        	 2000
#define RC_MID_PULSE        	 1500

// 角度范围-------------------------------------------------------------------
#define ANGLE_MIN             	-90
#define ANGLE_MAX             	 90

//脱钩舵机角度----------------------------------------------------------------
#define DECOUPLER_START_LEFT_ANGLE	 40	   //脱钩舵机挂钩角度
#define DECOUPLER_STOP_LEFT_ANGLE	 115   //脱钩舵机释放角度
#define DECOUPLER_START_RIGHT_ANGLE	 115
#define DECOUPLER_STOP_RIGHT_ANGLE	 10

// 飞特舵机映射参数-----------------------------------------------------------
/*参考点位
#define SERVO_MIN                1024      //飞特舵机限幅最小值
#define SERVO_MAX                3072      //飞特舵机限幅最大值
#define SERVO_MID                2048      //飞特舵机中位点*/
/*实际点位*/
#define SERVO_MIN                1600      //飞特舵机限幅最小值
#define SERVO_MAX                3000      //飞特舵机限幅最大值
#define SERVO_MID                2355      //飞特舵机中位点

#define SERVO_RANGE              2048      // 3072-1024
#define ANGLE_RANGE              180       // 90 - (-90)
#define ANGLE_TO_SERVO_FACTOR  (SERVO_RANGE / ANGLE_RANGE)  // ≈11.3778
//#define ANGLE_TO_SERVO_FACTOR     5

#define SERVO_ROLL_ID            1   
#define SERVO_PITCH_ID 	        2   

// PID 参数-------------------------------------------------------------------
#define KP  1.2f   // 比例增益
#define KI  0.0f    // 积分增益（消除静差）
#define KD  0.0f    // 微分增益（角速度阻尼）

// 积分限幅，防止饱和---------------------------------------------------------
#define INTEGRAL_LIMIT 50.0f

// 低通滤波系数 (用于角度测量，减小噪声)--------------------------------------
#define ANGLE_LPF_ALPHA 1.0f   // 值越小越平滑，但响应变慢，0.2~0.5

#define RX_BUF_SIZE 256
static uint8_t protocol_rx_buf[RX_BUF_SIZE];

/* USER CODE END PD */


/* USER CODE BEGIN PV */
// 脱钩舵机状态机变量----------------------------------------------------------
typedef enum {
    DECOUPLER_START = 0,   // 挂钩（0°）
    DECOUPLER_STOP  = 1    // 脱钩（90°）
} DECOUPLER_State_t;

DECOUPLER_State_t targetDecouplerState;  // 目标状态（由遥控器或手动按键决定）
int manualOverride = 0;                  // 手动覆盖标志：1表示正在手动脱钩，0表示由遥控器控制

// 陀螺仪变量------------------------------------------------------------------
float gyro_bias[3] = {0,0,0};

uint32_t last_tick = 0;
float dt = 0.01f;  

uint8_t mpu9250_ok = 0;  // 0: 失败/未初始化, 1: 正常

// 心跳监控（用于灯光）
static uint32_t last_heartbeat_tick = 0;
#define HEARTBEAT_TIMEOUT_MS 3000   // 与 mount_monitor 保持一致

static uint8_t last_main_id = 0xFF;  // 初始值不同于任何有效 ID
/* USER CODE END PV */

void SystemClock_Config(void);
/* USER CODE BEGIN PFP */
void CheckKeys(void);
uint8_t MPU9250_Reinit(void);
void on_frame_received(uint8_t main_id, uint8_t sub_id, uint8_t type,uint8_t *data, uint8_t len);
void on_mount_state_change(MM_FaultLevel_t level, MM_StateIndex_t state);
static void MPU9250_CalibrateGyro(MPU9250_HandleTypeDef *dev, float *bias, uint16_t samples);
void Servo_Test(void);

/* USER CODE END PFP */

/* USER CODE BEGIN 0 */
// 简单调试打印函数（阻塞式发送字符串）-----------------------------------------
void Debug_Print(const char *str)
{
    HAL_UART_Transmit(&huart4, (uint8_t*)str, strlen(str), HAL_MAX_DELAY);
}

// 带格式的打印（使用sprintf）--------------------------------------------------
void Debug_Printf(const char *format, ...)
{
    char buffer[128];
    va_list args;
    va_start(args, format);
    vsnprintf(buffer, sizeof(buffer), format, args);
    va_end(args);
    HAL_UART_Transmit(&huart4, (uint8_t*)buffer, strlen(buffer), HAL_MAX_DELAY);
}

void on_frame_received(uint8_t main_id, uint8_t sub_id, uint8_t type,
                       uint8_t *data, uint8_t len)
{
    if (type == 0x01) {
        // 心跳包：通知挂载监控
        MM_OnHeartbeatReceived();
		last_heartbeat_tick = HAL_GetTick(); // 新增：记录心跳时间
/*   	 数据包：根据 (main_id, sub_id) 分发挂载类型
	
	   桂载种类:SDC      	--- 	Serial DataDisconnection	未连接
				UAV-APT    	--- 	UAV Airdrop Payload Type	通用空役类挂载
				UAV-AB-PL	---		UAV Airborne Payload		通用空中使用类挂载
				UAV-UD-PL	---		UAV User-Defined Payload
				UAV-AUT-PL	---		UAV Autonomous Payload
				UPT			---		Undefined Payload Type
*/
        // 挂载类型显示（仅在类型变化时更新 OSD）
        if (main_id != last_main_id) {
            last_main_id = main_id;
            switch (main_id) {
                case 0x01:
                    OSD_Disply_String(4, 7, "UAV-APT");
                    OSD_Disply_String(5, 7, "ON ");
                    break;
                case 0x02:
                    OSD_Disply_String(4, 7, "UAV-AB-PL");
                    OSD_Disply_String(5, 7, "ON ");
                    break;
                default:
                    // 未知类型可显示默认字符串
                    OSD_Disply_String(4, 7, "UPT");
                    OSD_Disply_String(5, 7, "ERR");
                    break;
            }
        }
        // 打印调试信息
        Debug_Printf("Heartbeat from (0x%02X,0x%02X)\r\n", main_id, sub_id);
    }
    else if (type == 0x02) {

        switch (main_id) {
            case 0x01:  //数据处理

                break;
            case 0x02:  //数据处理

                break;
            default:
                break;
        }
    }
    
}
//按键检测----------------------------------------------------------------------
void CheckKeys(void) {
    static uint32_t lastKeyTime = 0;
    static uint8_t last_micro_state = 0;  // 上次微动状态（默认拔出，低电平）
    uint32_t now = HAL_GetTick();
    if ((now - lastKeyTime) < 200) return;
    
    // 手动脱钩按键
    if (HAL_GPIO_ReadPin(MANUAL_REMOVAL_GPIO_Port, MANUAL_REMOVAL_Pin) == GPIO_PIN_RESET) {
        manualOverride = 1;
        targetDecouplerState = DECOUPLER_STOP;
        lastKeyTime = now;
    } else {
        manualOverride = 0;
		lastKeyTime = now;
    }

	// 子挂载接入检测（微动开关 A，高电平表示插入））
	uint8_t micro_state = HAL_GPIO_ReadPin(MICROSWITCH_A_GPIO_Port, MICROSWITCH_A_Pin);

	// 上升沿检测（插入）
	if (micro_state == GPIO_PIN_SET && last_micro_state == GPIO_PIN_RESET) {
		// 彻底重置串口3
		HAL_UART_DMAStop(&huart3);
		__HAL_UART_CLEAR_IDLEFLAG(&huart3);
		// 清空接收缓冲区
		memset(protocol_rx_buf, 0, RX_BUF_SIZE);
		// 重新初始化协议库
		PROTOCOL_Init(&huart3, protocol_rx_buf, RX_BUF_SIZE);
		PROTOCOL_RegisterCallback(MAIN_ID_ANY, SUB_ID_ANY, on_frame_received);
		Debug_Print("Mount inserted, UART3 reset\r\n");
		last_micro_state = GPIO_PIN_SET;
	}
	// 下降沿检测（拔出）
	else if (micro_state == GPIO_PIN_RESET && last_micro_state == GPIO_PIN_SET) {
		// 拔出时也重置串口，以便下次插入正常工作
		HAL_UART_DMAStop(&huart3);
		__HAL_UART_CLEAR_IDLEFLAG(&huart3);
		PROTOCOL_Init(&huart3, protocol_rx_buf, RX_BUF_SIZE);
		PROTOCOL_RegisterCallback(MAIN_ID_ANY, SUB_ID_ANY, on_frame_received);
		Debug_Print("Mount removed, UART3 reset\r\n");
		last_micro_state = GPIO_PIN_RESET;
	}
	
	// 如果 MPU9250 之前失败，尝试重新初始化
	if (!mpu9250_ok) {
		if (MPU9250_Reinit()) {
			mpu9250_ok = 1;
		}
	}
    lastKeyTime = now;
}
uint8_t MPU9250_Reinit(void) {
    HAL_StatusTypeDef status = MPU9250_Init(&hmpu9250);
    if (status != HAL_OK) {
        Debug_Print("MPU9250 初始化失败\r\n");
        return 0;
    }else {
			Debug_Print("MPU9250 初始化成功\r\n");
	}

    // 校准陀螺仪
    MPU9250_CalibrateGyro(&hmpu9250, gyro_bias, 100);
    float tmp = gyro_bias[0];
    gyro_bias[0] = gyro_bias[1];
    gyro_bias[1] = tmp;
    Debug_Printf("MPU9250 重新初始化成功，偏置 X=%.2f Y=%.2f Z=%.2f\r\n", 
                 gyro_bias[0], gyro_bias[1], gyro_bias[2]);
    // 重新初始化卡尔曼滤波器
    MPU9250_Kalman_Init(&kalman_roll, 0.001f, 0.003f, 0.03f);
    MPU9250_Kalman_Init(&kalman_pitch, 0.001f, 0.003f, 0.03f);
    return 1;
}
void on_mount_state_change(MM_FaultLevel_t level, MM_StateIndex_t state)
{
    // 仅打印状态变化（灯光已由独立逻辑控制）
    Debug_Printf("[MOUNT] Level: %d, State: %d\r\n", level, state);
}
/* USER CODE END 0 */

/**
  * @brief  The application entry point.
  * @retval int
  */
int main(void)
{

  /* MCU Configuration--------------------------------------------------------*/

  /* Reset of all peripherals, Initializes the Flash interface and the Systick. */
  HAL_Init();

  /* Configure the system clock */
  SystemClock_Config();

  /* Initialize all configured peripherals */
  MX_GPIO_Init();
  MX_DMA_Init();
  MX_I2C1_Init();
  MX_SPI1_Init();
  MX_TIM2_Init();
  MX_TIM3_Init();
  MX_TIM4_Init();
  MX_UART4_Init();
  MX_UART5_Init();
  MX_USART3_UART_Init();
  /* USER CODE BEGIN 2 */
	HAL_StatusTypeDef status;
	AT7456_Init(&hspi1,GPIOB,GPIO_PIN_0);
	HAL_Delay(2000);
	
	Debug_Print("\r\n========== MPU9250舵机云台启动 ==========\r\n");
	//============================ 1. 初始化LED  ========================================================================
	HAL_GPIO_WritePin(B_GPIO_Port, B_Pin, GPIO_PIN_SET); // 自检指示灯（默认点亮，板载PC13高电平点亮，）

	
	//============================ 2. 初始化MPU9250  ====================================================================
	hmpu9250.hi2c = &hi2c1;
	mpu9250_ok = MPU9250_Reinit();
	if (!mpu9250_ok) {
		HAL_GPIO_WritePin(B_GPIO_Port, B_Pin, GPIO_PIN_RESET); 
		Debug_Print("MPU9250 初始化失败，将定期重试\r\n");
	}
	
	
	//============================ 5. 测试舵机发送（验证舵机通信）  =====================================================
	Debug_Print("测试舵机1（ID=1）移动到中位...\r\n");
	HAL_StatusTypeDef servo_status = Servo_WritePosEx(&huart5, SERVO_ROLL_ID, SERVO_MID, 200);
	if (servo_status != HAL_OK) {
			Debug_Print("舵机指令发送失败\r\n");
	HAL_GPIO_WritePin(B_GPIO_Port, B_Pin, GPIO_PIN_RESET);  // 自检指示灯熄灭
	} else {
			Debug_Print("舵机指令发送成功！\r\n");
	}
	Servo_Test();
	
	
	//============================ 6. 初始化遥控器PWM输入 (TIM2）  ======================================================
	PWM_Input_Init(&rc_ch[0], &htim2, TIM_CHANNEL_1, NULL);
	PWM_Input_Init(&rc_ch[1], &htim2, TIM_CHANNEL_2, NULL);
	PWM_Input_Init(&rc_ch[2], &htim2, TIM_CHANNEL_3, NULL);
	PWM_Input_Init(&rc_ch[3], &htim2, TIM_CHANNEL_4, NULL);
	
	PWM_Input_Init(&rc_ch3[0], &htim3, TIM_CHANNEL_1, NULL);
	PWM_Input_Init(&rc_ch3[1], &htim3, TIM_CHANNEL_2, NULL);
	PWM_Input_Init(&rc_ch3[2], &htim3, TIM_CHANNEL_3, NULL);
	PWM_Input_Init(&rc_ch3[3], &htim3, TIM_CHANNEL_4, NULL);

	
	//============================ 7. 初始化9g舵机 (TIM4 CH1、CH2) ======================================================
	Servo_Init(&servo9g_Left, &htim4, TIM_CHANNEL_1, 500, 2500);//0~180°
	Servo_Start(&servo9g_Left);
	Servo_SetAngle(&servo9g_Left, DECOUPLER_START_LEFT_ANGLE);
	
	Servo_Init(&servo9g_Right, &htim4, TIM_CHANNEL_2, 500, 2500);//0~180°
	Servo_Start(&servo9g_Right);
	Servo_SetAngle(&servo9g_Right, DECOUPLER_START_RIGHT_ANGLE);
	
	targetDecouplerState = DECOUPLER_START;
	manualOverride = 0;
	
	
	//============================ 8. 初始化OSD界面  ===================================================================
	/*挂载自稳（GBS）Gimbal Stabilization*/
		OSD_Disply_String(2,2,"GBS:");
		OSD_Disply_String(2,7,"ON ");
	/*挂载状态（GBT）Gimbal Status*/
		OSD_Disply_String(3,2,"GBT:");
		OSD_Disply_String(3,7,"SU ");
	/*挂载种类（GBK）Gimbal Kind*/
		OSD_Disply_String(4,2,"GBK:");
		OSD_Disply_String(4,7,"SRC");
	/*挂载回传数据（GDD）Gimbal Downlink Data*/
		OSD_Disply_String(5,2,"GDD:");
		OSD_Disply_String(5,7,"ON ");
		
		Disply_osd();


	//============================ 9. 配置挂载监测库  ==================================================================
    monitor_cfg.en_port = EN_GPIO_Port;
    monitor_cfg.en_pin = EN_Pin;
    monitor_cfg.micro_port = MICROSWITCH_A_GPIO_Port;
    monitor_cfg.micro_pin = MICROSWITCH_A_Pin;
    monitor_cfg.heartbeat_huart = &huart3;
    monitor_cfg.heartbeat_timeout_ms = 3000;
    
    MM_Init(&monitor_cfg, on_mount_state_change);
    
	
	//============================ 10. 初始化 protocol 库 ==============================================================
	PROTOCOL_Init(&huart3, protocol_rx_buf, RX_BUF_SIZE);
	PROTOCOL_RegisterCallback(MAIN_ID_ANY, SUB_ID_ANY, on_frame_received);


	//============================ 11. 初始化完成，自检指示灯常亮1S  =============================================
	HAL_GPIO_WritePin(B_GPIO_Port, B_Pin, GPIO_PIN_SET); 
	HAL_Delay(1000);
	uint32_t loop_count = 0;
	
	
	//============================ 12. 记录起始时间  ===================================================================
	last_tick = HAL_GetTick();


  /* USER CODE END 2 */

  /* Infinite loop */
  /* USER CODE BEGIN WHILE */
  while (1)
  {
    // ========== 1. 时间计算 =============================================
    uint32_t now = HAL_GetTick();
    dt = (now - last_tick) / 1000.0f;
    if (dt < 0.001f) dt = 0.001f;
    last_tick = now;
	  
	// 周期性重试 MPU9250 初始化（如果之前失败）
	static uint32_t last_mpu_retry = 0;
	if (!mpu9250_ok && (HAL_GetTick() - last_mpu_retry > 2000)) {
		last_mpu_retry = HAL_GetTick();
		if (MPU9250_Reinit()) {
			mpu9250_ok = 1;
//			HAL_GPIO_WritePin(SELF_CHECK_GPIO_Port, SELF_CHECK_Pin, GPIO_PIN_SET);
		}
	}

	/* 非阻塞地处理挂载状态机（建议每 20~50ms 调用一次） */
	static uint32_t last_mm_time = 0;
	if (HAL_GetTick() - last_mm_time >= 50) {
		last_mm_time = HAL_GetTick();
		MM_Process();
	}
	
	    // 静态变量，用于保持上一次的滤波角度和角速度（跨循环使用）
    static float smooth_roll = 0, smooth_pitch = 0;
    static float gx = 0, gy = 0;
	
    // ========== 2. 读取传感器数据并处理 =================================
    if (mpu9250_ok) {
        HAL_StatusTypeDef accel_status = MPU9250_ReadAccel(&hmpu9250);
        HAL_StatusTypeDef gyro_status = MPU9250_ReadGyro(&hmpu9250);
        if (accel_status != HAL_OK || gyro_status != HAL_OK) {
            Debug_Print("传感器读取失败！\r\n");
            mpu9250_ok = 0;  // 标记失败，后续重试
            // 保持上一次的 smooth_roll, smooth_pitch, gx, gy 不变
        } else {
            // 交换 X/Y 轴
            float ax = hmpu9250.accel[1];
            float ay = hmpu9250.accel[0];
            float az = hmpu9250.accel[2];
            gx = hmpu9250.gyro[1] - gyro_bias[1];
            gy = hmpu9250.gyro[0] - gyro_bias[0];
            float gz = hmpu9250.gyro[2] - gyro_bias[2];

            // 加速度计角度
            float accel_roll  = MPU9250_AccelToAngle(ax, ay, az, 'r');
            float accel_pitch = MPU9250_AccelToAngle(ax, ay, az, 'p');

            // 卡尔曼滤波更新
            float filtered_roll  = MPU9250_Kalman_Update(&kalman_roll,  accel_roll,  gx, dt);
            float filtered_pitch = MPU9250_Kalman_Update(&kalman_pitch, accel_pitch, gy, dt);

            // 修正符号
            filtered_roll  = -filtered_roll;
            filtered_pitch = -filtered_pitch;

            // 低通滤波
            float alpha = ANGLE_LPF_ALPHA;
            smooth_roll  = alpha * filtered_roll  + (1 - alpha) * smooth_roll;
            smooth_pitch = alpha * filtered_pitch + (1 - alpha) * smooth_pitch;
        }
    } else {
        // 传感器未就绪，保持上次值，可加短暂延时避免空转
        HAL_Delay(5);
    }

	
    // ========== 3. 读取遥控器 PWM 脉宽 ===================================
	uint16_t raw_ch1 = PWM_Input_GetPulse(&rc_ch[0]);
	uint16_t raw_ch2 = PWM_Input_GetPulse(&rc_ch[1]);
	uint16_t raw_ch3 = PWM_Input_GetPulse(&rc_ch[2]);
	uint16_t raw_ch4 = PWM_Input_GetPulse(&rc_ch[3]);

	// 所有通道统一有效性判断（有效范围 900~2100µs）
	if (raw_ch1 < 900 || raw_ch1 > 2100) raw_ch1 = RC_MID_PULSE;
	if (raw_ch2 < 900 || raw_ch2 > 2100) raw_ch2 = RC_MID_PULSE;
	if (raw_ch3 < 900 || raw_ch3 > 2100) raw_ch3 = RC_MID_PULSE;
	if (raw_ch4 < 900 || raw_ch4 > 2100) raw_ch4 = RC_MID_PULSE;

    // 限幅到有效范围
	if (raw_ch1 < RC_MIN_PULSE) raw_ch1 = RC_MIN_PULSE;
	if (raw_ch1 > RC_MAX_PULSE) raw_ch1 = RC_MAX_PULSE;
	if (raw_ch2 < RC_MIN_PULSE) raw_ch2 = RC_MIN_PULSE;
	if (raw_ch2 > RC_MAX_PULSE) raw_ch2 = RC_MAX_PULSE;
	if (raw_ch3 < RC_MIN_PULSE) raw_ch3 = RC_MIN_PULSE;
	if (raw_ch3 > RC_MAX_PULSE) raw_ch3 = RC_MAX_PULSE;
	if (raw_ch4 < RC_MIN_PULSE) raw_ch4 = RC_MIN_PULSE;
	if (raw_ch4 > RC_MAX_PULSE) raw_ch4 = RC_MAX_PULSE;

    // 将摇杆（通道1、2）映射到目标角度（-90° ~ 90°）
    float target_roll  = (float)(raw_ch1 - RC_MID_PULSE) * ANGLE_RANGE / (RC_MAX_PULSE - RC_MIN_PULSE);
    float target_pitch = (float)(raw_ch2 - RC_MID_PULSE) * ANGLE_RANGE / (RC_MAX_PULSE - RC_MIN_PULSE);

    // 自稳模式开关（通道4）
    uint8_t stabilize_mode = (raw_ch3 < STABILIZE_THRESHOLD) ? 1 : 0;


    // ========== 4. 脱钩舵机控制（通道3 + 手动按键） ======================
	CheckKeys();
    if (!manualOverride) {
        if (raw_ch4 > SWITCH_THRESHOLD)
            targetDecouplerState = DECOUPLER_STOP;
        else
            targetDecouplerState = DECOUPLER_START;
    }
    Servo_SetAngle(&servo9g_Left, (targetDecouplerState == DECOUPLER_STOP) ? DECOUPLER_STOP_LEFT_ANGLE : DECOUPLER_START_LEFT_ANGLE);
    Servo_SetAngle(&servo9g_Right, (targetDecouplerState == DECOUPLER_STOP) ? DECOUPLER_STOP_RIGHT_ANGLE : DECOUPLER_START_RIGHT_ANGLE);

	
    // ========== 5. 云台控制（自稳 / 手动） ===============================
    int16_t roll_pos, pitch_pos;

    static float integral_roll = 0, integral_pitch = 0;

	if (stabilize_mode) {
		// 增稳模式：误差 = 机身角度 - 目标角度（目标角度通常为0）
		float error_roll  = smooth_roll - target_roll;
		float error_pitch = smooth_pitch - target_pitch;
		// 纯比例，KP=1，无积分微分
		roll_pos  = SERVO_MID - (int16_t)(error_roll  * ANGLE_TO_SERVO_FACTOR);
		pitch_pos = SERVO_MID - (int16_t)(error_pitch * ANGLE_TO_SERVO_FACTOR);
		// 更新 OSD
		OSD_Disply_String(2, 7, "ON ");
	}
    else
    {
        // 手动模式：直接映射遥控器角度
        roll_pos  = SERVO_MID + (int16_t)(target_roll  * ANGLE_TO_SERVO_FACTOR);
        pitch_pos = SERVO_MID + (int16_t)(target_pitch * ANGLE_TO_SERVO_FACTOR);

        // 清零积分，避免切回自稳时跳变
        integral_roll = 0;
        integral_pitch = 0;

        OSD_Disply_String(2, 7, "OFF");
    }

    // 限幅到舵机安全范围
    if (roll_pos < SERVO_MIN) roll_pos = SERVO_MIN;
    if (roll_pos > SERVO_MAX) roll_pos = SERVO_MAX;
    if (pitch_pos < SERVO_MIN) pitch_pos = SERVO_MIN;
    if (pitch_pos > SERVO_MAX) pitch_pos = SERVO_MAX;

	
    // ========== 6. 发送舵机指令 ===========================================
    Servo_WritePosEx(&huart5, SERVO_ROLL_ID,  roll_pos,  0);
    Servo_WritePosEx(&huart5, SERVO_PITCH_ID, pitch_pos, 0);

	
	// ========== 7. 子挂载控制信号 (TIM3 CH1~CH4) ==========
	// 定义通道对应的子 ID
	const uint8_t sub_ids[] = {0x01, 0x02, 0x03, 0x04};
	static uint16_t last_pulse[4] = {0};

	for (int i = 0; i < 4; i++) {
		uint16_t pulse = PWM_Input_GetPulse(&rc_ch3[i]);
		
		// 信号有效性判断：无效则强制设为中位值 1500
		if (pulse < 900 || pulse > 2100) {
			pulse = 1500;
		} else {
			// 限幅到标准遥控器范围 1000~2000
			if (pulse < RC_MIN_PULSE) pulse = RC_MIN_PULSE;
			if (pulse > RC_MAX_PULSE) pulse = RC_MAX_PULSE;
		}
		
		// 仅在数值变化时发送
		if (pulse != last_pulse[i]) {
			last_pulse[i] = pulse;
			uint8_t data[2] = {
				(uint8_t)(pulse & 0xFF),
				(uint8_t)((pulse >> 8) & 0xFF)
			};
			PROTOCOL_SendFrame(0x01, sub_ids[i], 0x02, data, 2);
		}
	}

		
	// 判断是否已接入（EN引脚有效）
	uint8_t mount_connected = (HAL_GPIO_ReadPin(EN_GPIO_Port, EN_Pin) == GPIO_PIN_RESET); // 假设低电平接入

	if (!mount_connected) {
		// 未接入 -> 黄灯（空闲等待）
		HAL_GPIO_WritePin(R_GPIO_Port, R_Pin, GPIO_PIN_SET);
		HAL_GPIO_WritePin(G_GPIO_Port, G_Pin, GPIO_PIN_SET);
		HAL_GPIO_WritePin(B_GPIO_Port, B_Pin, GPIO_PIN_RESET);
	} else {
		// 已接入，检查故障条件（心跳超时）
		uint8_t heartbeat_ok = (HAL_GetTick() - last_heartbeat_tick) < HEARTBEAT_TIMEOUT_MS;
		if (!heartbeat_ok) {
			// 已接入但心跳丢失 -> 红灯（故障）
			HAL_GPIO_WritePin(R_GPIO_Port, R_Pin, GPIO_PIN_SET);
			HAL_GPIO_WritePin(G_GPIO_Port, G_Pin, GPIO_PIN_RESET);
			HAL_GPIO_WritePin(B_GPIO_Port, B_Pin, GPIO_PIN_RESET);
		} else {
			// 已接入且心跳正常，根据脱钩状态决定颜色
			if (targetDecouplerState == DECOUPLER_STOP) {
				// 脱钩状态 -> 黄灯（正常工作状态，不算故障）
				HAL_GPIO_WritePin(R_GPIO_Port, R_Pin, GPIO_PIN_SET);
				HAL_GPIO_WritePin(G_GPIO_Port, G_Pin, GPIO_PIN_SET);
				HAL_GPIO_WritePin(B_GPIO_Port, B_Pin, GPIO_PIN_RESET);
				last_main_id = 0xFF;
				OSD_Disply_String(3,7,"SU ");
				OSD_Disply_String(4,7,"SDC                   ");
				OSD_Disply_String(5,7,"OFF");
			} else {
				// 正常接入且未脱钩 -> 绿灯
				HAL_GPIO_WritePin(R_GPIO_Port, R_Pin, GPIO_PIN_RESET);
				HAL_GPIO_WritePin(G_GPIO_Port, G_Pin, GPIO_PIN_SET);
				HAL_GPIO_WritePin(B_GPIO_Port, B_Pin, GPIO_PIN_RESET);
				OSD_Disply_String(3,7,"SC ");
			}
		}
	}
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

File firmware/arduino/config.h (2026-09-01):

#ifndef CONFIG_H
#define CONFIG_H

// 串口配置
#define SERIAL_PORT         Serial2
#define RX2_PIN             16
#define TX2_PIN             17
#define BAUD_RATE           115200

// 舵机引脚
#define SERVO1_PIN          2      // 子ID=1
#define SERVO2_PIN          4      // 子ID=2

// 舵机1（子ID=1）配置
#define SERVO1_PWM_THRESHOLD    1750   // 大于此值转高角度，否则转低角度
#define SERVO1_ANGLE_HIGH       180    // 高角度（当PWM > 阈值）
#define SERVO1_ANGLE_LOW        0      // 低角度（当PWM ≤ 阈值）

// 舵机2（子ID=2）配置
#define SERVO2_PWM_THRESHOLD    1750   // 示例：阈值1500
#define SERVO2_ANGLE_HIGH       180     // 大于1500时转90度
#define SERVO2_ANGLE_LOW        0      // 否则转0度

// 心跳包配置
#define HEARTBEAT_INTERVAL  2000
#define HEARTBEAT_DATA      0xAA

// 协议定义
#define FRAME_HEAD          0xAA
#define FRAME_TAIL          0x55
#define TYPE_HEARTBEAT      0x01
#define TYPE_DATA           0x02

#endif

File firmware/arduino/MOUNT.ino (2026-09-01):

#include "config.h"
#include "my_protocol.h"
#include "servo_control.h"

unsigned long last_heartbeat_time = 0;
uint8_t heartbeat_counter = 0;

void on_protocol_frame(uint8_t master_id, uint8_t sub_id, const uint8_t *data, uint8_t len) {
    if (master_id == 1 && len == 2) {
        uint16_t pwm = data[0] | (data[1] << 8);
        uint8_t angle = 0;
        
        switch (sub_id) {
            case 1:
                angle = (pwm > SERVO1_PWM_THRESHOLD) ? SERVO1_ANGLE_HIGH : SERVO1_ANGLE_LOW;
                servo_set_angle(1, angle);
                Serial.printf("Servo1 PWM=%d -> %d deg (th=%d)\n", pwm, angle, SERVO1_PWM_THRESHOLD);
                break;
            case 2:
                angle = (pwm > SERVO2_PWM_THRESHOLD) ? SERVO2_ANGLE_HIGH : SERVO2_ANGLE_LOW;
                servo_set_angle(2, angle);
                Serial.printf("Servo2 PWM=%d -> %d deg (th=%d)\n", pwm, angle, SERVO2_PWM_THRESHOLD);
                break;
            default:
                Serial.printf("Unknown sub_id %d\n", sub_id);
                break;
        }
    }
}

void setup() {
    Serial.begin(115200);
    Serial.println("ESP32 Dual Servo Start");
    SERIAL_PORT.begin(BAUD_RATE, SERIAL_8N1, RX2_PIN, TX2_PIN);
    servo_init();
    protocol_init(on_protocol_frame);
    last_heartbeat_time = millis();
    Serial.println("Setup done");
}

void loop() {
    while (SERIAL_PORT.available()) {
        uint8_t b = SERIAL_PORT.read();
        protocol_parse_byte(b);
    }
    if (millis() - last_heartbeat_time >= HEARTBEAT_INTERVAL) {
        last_heartbeat_time = millis();
        protocol_send_heartbeat(heartbeat_counter++);
    }
}

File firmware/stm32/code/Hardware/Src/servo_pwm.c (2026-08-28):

#include "servo_pwm.h"

void Servo_Init(Servo_Handle *servo, TIM_HandleTypeDef *htim, uint32_t channel,
                uint16_t min_pulse, uint16_t max_pulse)
{
    servo->htim = htim;
    servo->channel = channel;
    servo->min_pulse = min_pulse;
    servo->max_pulse = max_pulse;
    servo->min_angle = 0;
    servo->max_angle = 180;
}

void Servo_SetAngle(Servo_Handle *servo, int16_t angle)
{
    if (angle < servo->min_angle) angle = servo->min_angle;
    if (angle > servo->max_angle) angle = servo->max_angle;

    uint16_t pulse = servo->min_pulse +
                     (uint32_t)(angle - servo->min_angle) *
                     (servo->max_pulse - servo->min_pulse) /
                     (servo->max_angle - servo->min_angle);

    Servo_SetPulse(servo, pulse);
}

void Servo_SetPulse(Servo_Handle *servo, uint16_t pulse_us)
{
    __HAL_TIM_SET_COMPARE(servo->htim, servo->channel, pulse_us);
}

void Servo_Start(Servo_Handle *servo)
{
    HAL_TIM_PWM_Start(servo->htim, servo->channel);
}

void Servo_Stop(Servo_Handle *servo)
{
    HAL_TIM_PWM_Stop(servo->htim, servo->channel);
}

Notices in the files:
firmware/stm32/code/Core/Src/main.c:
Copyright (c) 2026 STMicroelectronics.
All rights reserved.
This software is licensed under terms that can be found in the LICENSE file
